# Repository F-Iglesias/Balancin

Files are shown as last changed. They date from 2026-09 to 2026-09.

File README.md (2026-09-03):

# A hand-made self balancing robot!

It balances itself with a PID control, measuring the angle 

## Third and final prototype


You can see a video of the robot moving [here](https://www.youtube.com/watch?v=WksrDXhgYMs)

### Main board



### Encoders (3D printed and designed by me)




<p align="center">

</p>

## Second prototype



[Here](https://youtube.com/shorts/iVz-gH_mcks?feature=share) is a video.

For this prototype I designed a simpler encoder, but since it was not able to read the direction in which the wheels rotated, it was useless for its purpose, so I discarded that design.

Captura encoder v1

## First prototype

Sadly I lost all the photos I had, but here are two videos:

[Video 1](https://youtube.com/shorts/Z38a0RHIttk?feature=share)

[Video 2](https://youtube.com/shorts/8MTNevPrN3k?feature=share)

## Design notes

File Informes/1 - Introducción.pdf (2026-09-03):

### Taller de Electrónica

Introducción

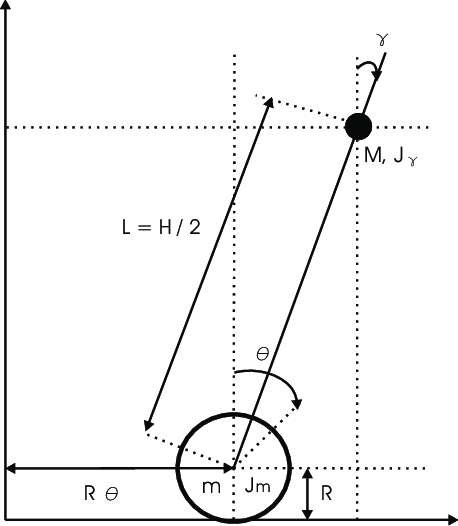
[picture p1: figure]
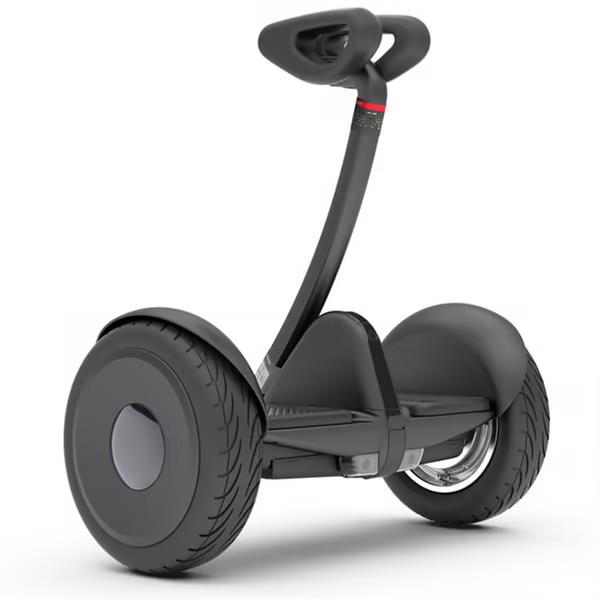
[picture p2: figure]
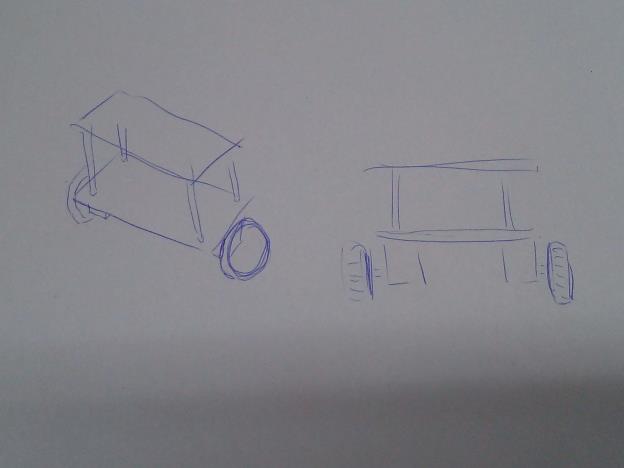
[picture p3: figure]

2024 1

## Introducción

La idea de nuestro proyecto es un robot equilibrista. Más específicamente, un robot que puede mantenerse equilibrado y maniobrar utilizando dos ruedas, que además pueda controlarse mediante Bluetooth.

Este robot puede modelarse como un péndulo invertido de dos ruedas: un sistema que consiste de un péndulo montado sobre dos ruedas que pueden girar libremente (fig 1.a). Este sistema es inestable, por lo que es muy utilizado para las pruebas de algoritmos de control. Un ejemplo comercial de este tipo de robots es el Segway (fig 1.b)

Fig 1.a: Esquema del péndulo invertido | Fig 1.b: Segway

Se puede ver el primer boceto de nuestro proyecto:

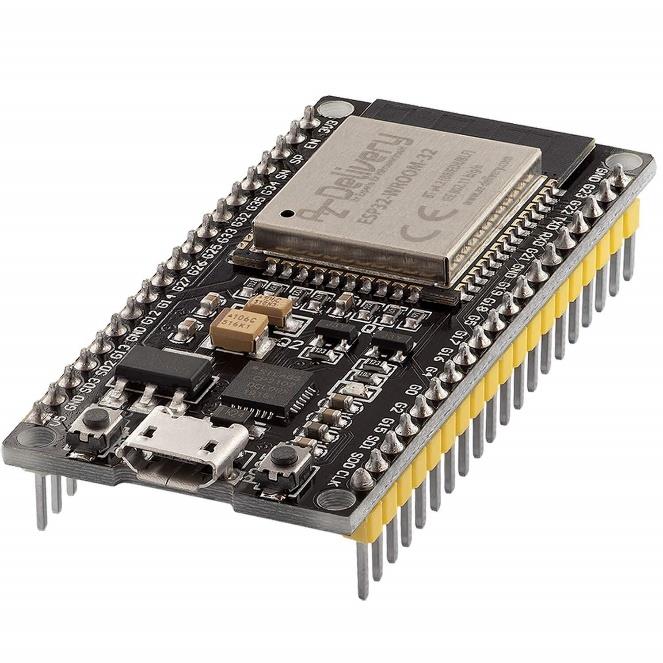
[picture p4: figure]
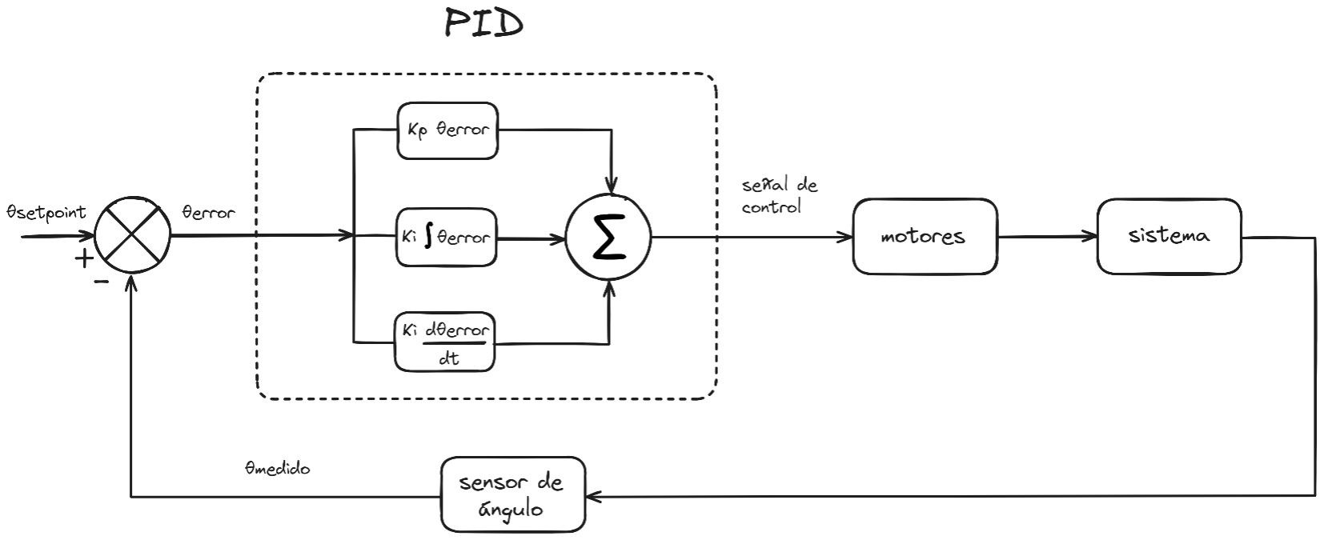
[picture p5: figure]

2024 2

La idea es que el robot mantenga el equilibrio controlando únicamente los motores. Claramente necesitamos cierta información del exterior, que obtendremos a partir de sensores. Para leer y procesar la información de los sensores e implementar la comunicación Bluetooth, usaremos un microcontrolador programable: el ESP32. Elegimos este porque ya viene con Bluetooth integrado y tiene librerías que nos facilitan implementar la comunicación, además de que puede programarse en el framework de Arduino con PlatformIO

Investigando, vimos que uno de los algoritmos de control más usados es el control PID, que podemos representar en el siguiente diagrama.

Vamos a considerar que θ es el ángulo de inclinación el robot. El setpoint será el ángulo al que queremos llegar, y el error la diferencia entre el setpoint y el ángulo medido.

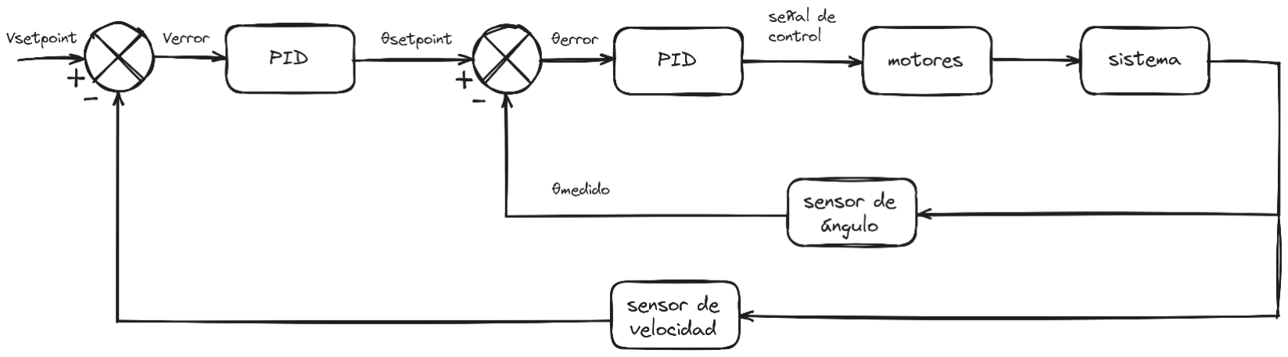
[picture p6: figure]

2024 3

θsetpoint − θmedido = θerror

El control PID (proporcional, integrativo, derivativo) es un sistema de control de lazo cerrado en el cual nuestra señal de control es una combinación lineal entre el error, su integral y su derivadal, dado por las constantes Kp, Ki y Kd.

señal de control = Kp ⋅ θerror + Ki ⋅ ∫ θerrordt + Kd ⋅

dθerror
dt

La eficacia de este sistema depende de qué tan bien ajustados estén los tres parámetros Kp, Ki y Kd

Ahora bien, si este sistema de lazo cerrado está bien afinado puede mantener al robot verticalmente de una forma muy estable, pero si queremos maniobrar (modificando el setpoint) el sistema se vuelve muy inestable. (checkear)

Se puede llegar a un sistema mucho más estable si añadimos otro lazo cerrado en cascada, que controle el setpoint de nuestro primer PID en función de la velocidad lineal del robot.
El sistema de se representa así:

Con esto ya hemos definido el algoritmo de control. Lo que queda es implementarlo en nuestro proyecto. Todos estos cálculos pueden realizarse fácilmente en el firmware, principalmente necesitamos es saber como:
- Controlar los motores
- Medir el angulo de inclinación
- Sintonizar el primer PID
- Medir la velocidad de las ruedas
- Sintonizar el segundo PID

En las siguientes partes veremos como hacer esto

2024 4

## Referencias

- https://es.wikipedia.org/wiki/Controlador_PID
- https://robotics.stackexchange.com/questions/17964/self-balancing-robot-pid-control-algorithm
- https://arxiv.org/ftp/arxiv/papers/2303/2303.12067.pdf

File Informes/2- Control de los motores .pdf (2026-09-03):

### Taller de Electrónica

Control PWM

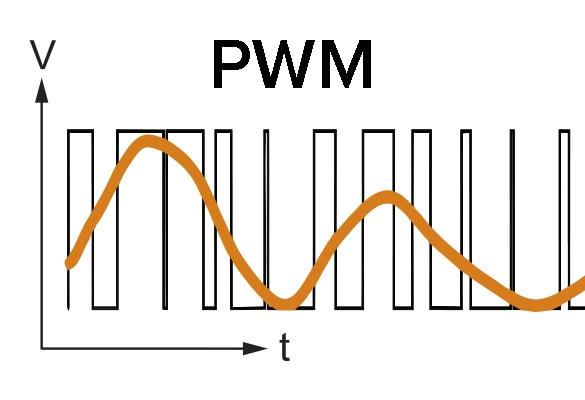
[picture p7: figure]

2024 1

## 2 - Control PWM

Para implementar correctamente nuestro péndulo invertido debemos tener una forma de controlar la velocidad de los motores desde nuestro microcontrolador.

La forma más común de hacer esto es mediante PWM (Modulación de ancho de pulso). El PWM es una técnica que consiste en generar una señal pulsante a frecuencia constante e ir variando el ciclo de trabajo..

Si conectamos un motor a un generador PWM, la velocidad del motor dependerá del ciclo de trabajo, es decir, que para un ciclo de trabajo fijo, el motor girará a velocidad constante. A frecuencias más altas, más preciso es nuestro control.

figura 2.1. La curva amarilla representa el valor promedio en cada momento de esta señal PWM

Entonces, lo que vamos a hacer es implementar un control PWM para el ESP32.

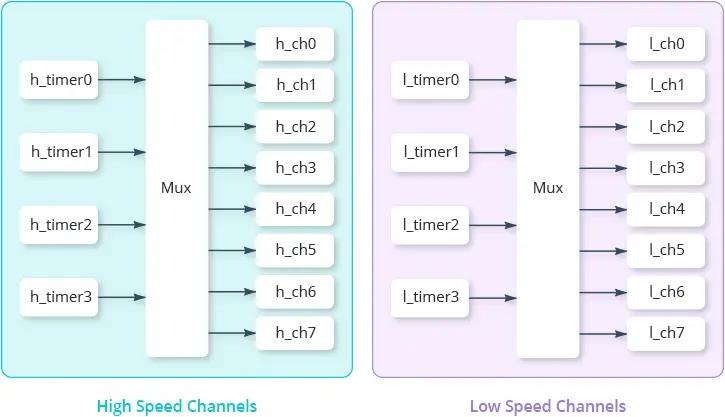
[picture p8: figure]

2024 2

## El código

El ESP32 tiene 16 canales internos de PWM, los primeros 8 de alta frecuencia y los otros de baja frecuencia.

Los canales de alta velocidad están implementados en el hardware, es decir que son independientes del procesador, mientras que los canales de baja frecuencia dependen del software para cambiar el ciclo de trabajo.

Como puede verse en la imagen anterior, cada 8 canales hay cuatro timers, por lo que cada temporizador es compartido por dos canales. Esto significa que los dos canales que compartan un mismo temporizador tendrán la misma frecuencia, pero su ciclo de trabajo se puede controlar de forma independiente. En nuestro caso esto no importa, ya que la frecuencia de PWM que vamos a usar para los motores va a ser la misma para cada salida.

Para generar una señal PWM, debemos “adjuntar” un canal de PWM a un pin GPIO. Es posible adjuntar el mismo canal a varios pines. El código es el siguiente:

2024 3

#include <Arduino.h>

//Definimos lo pines de salida del motor que se controla con un puente H

uint8_t pin1 = 2;

uint8_t pin2 = 16;

uint8_t ch0 = 0;

uint8_t ch1 = 1;

void setup()

{

int freq = 30000; //La frecuencia de la señal PWM. Usamos 30kHz ya que

está fuera de la frecuencia audible

int res = 1023; //La resolución del PWM

uint8_t res_bits = 10; //La misma resolución en bits

//Elegimos los canales de PWM

//Establece los pines como salida

pinMode(pin1, OUTPUT);

pinMode(pin2, OUTPUT);

//Establece la frecuencia y la resolución del PWM en los canales 0 y 1

ledcSetup(ch0, freq, res_bits);

ledcSetup(ch1, freq, res_bits);

//Adjunt los pines pin1 y pin2 a los canales ch0 y ch1, respectivamente

ledcAttachPin(pin1, ch0);

ledcAttachPin(pin2, ch1);

//Pone el ciclo de trabajo en 0 para que los motores estén apagados

ledcWrite(ch0, 0);

ledcWrite(ch1, 0);

}

Luego, en el loop, llamando a la función ledcWrite, podemos cambiar el ciclo de trabajo de los distintos pines.

2024 4

## Bibliografía

- https://lastminuteengineers.com/esp32-pwm-tutorial/#:~:text=PWM%20Channels,-Now%20let%20us&text=A%20channel%20represents%20a%20unique,and%208%20low-speed%20channels. (https://lastminuteengineers.com/esp32-pwm-tutorial/)
- https://randomnerdtutorials.com/esp32-pwm-arduino-ide/

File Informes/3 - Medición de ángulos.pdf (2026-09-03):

### Taller de Electrónica

Giróscopo - acelerómetro

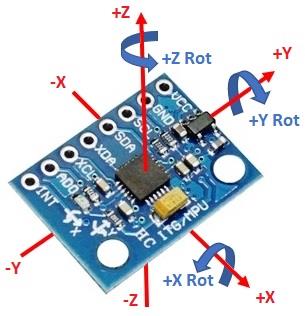
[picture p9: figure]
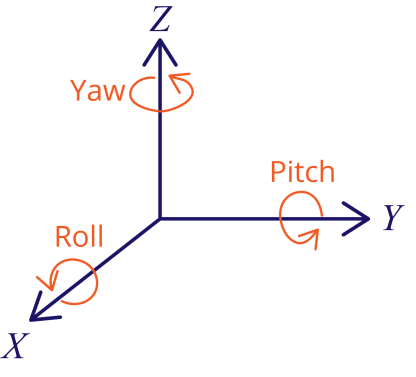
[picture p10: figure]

2024 1

## 3 - Unidad de medición inercial

Una unidad de medición inercial o IMU, es un dispositivo electrónico que mide e informa acerca de la velocidad, orientación y fuerzas gravitacionales de un aparato, usando una combinación de acelerómetros y giróscopos (wikipedia). (https://es.wikipedia.org/wiki/Unidad_de_medici%C3%B3n_inercial)

Para controlar a nuestro robot necesitamos saber su ángulo de inclinación. Lo más común es usar una IMU para esto. El módulo que usaremos es el MPU6050.

Los datos que nos da el MPU6050 son, la aceleración lineal y la velocidad angular en sus tres ejes (x, y, z). Como veremos más adelante, estos datos son suficientes para estimar el ángulo de inclinación de nuestro robot.

Convencionalmente, los ejes x, y, z se llaman roll, pitch y yaw.

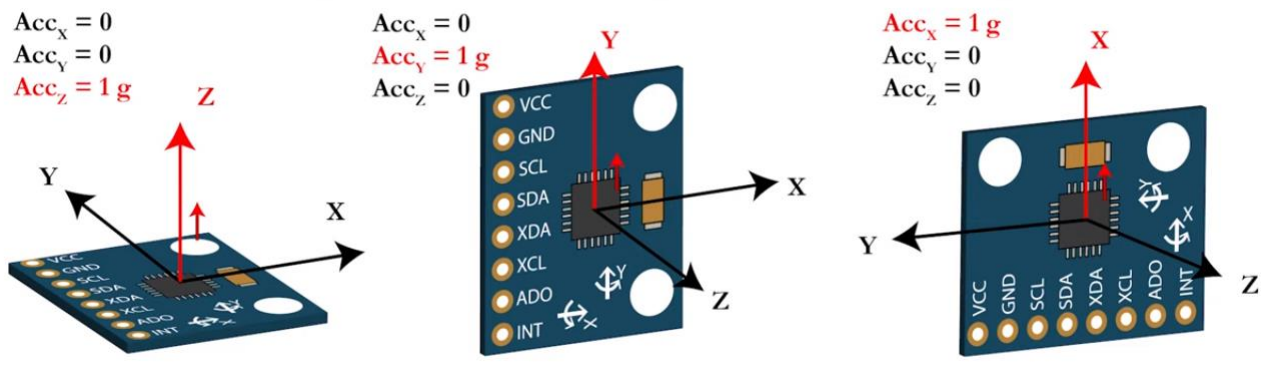
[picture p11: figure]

2024 2

## Midiendo la inclinación con el acelerómetro – método trigonométrico

Este método nos permite obtener una aproximación de los ángulos roll y pitch.

La fuerza de la gravedad siempre tiene la misma dirección, así que conocer su vector respecto a los ejes x, y, z del IMU nos permite conocer su orientación respecto al plano horizontal de la tierra.

Argumentos trigonométricos nos permiten llegar a las siguientes fórmulas:

θroll = arctan (
gy
√gx
2 + gz

2

)

θpitcℎ = arctan (
−gx
√gy
2 + gz

2

)

Donde gx, gy, gz
son las componentes de la gravedad en los ejes x, y, z del MPU. Véase que este método solo sirve para inclinaciones menores a ±90°. Y, en general, para ángulos muy cercanos a ±90° se vuelve impreciso por el comportamiento asintótico de vx √vy 2+vz

2

cuando el

vector v tiende a ser horizontal.

En el MPU6050, los ejes del acelerómetro funcionan como resortes, de modo tal que cualquier fuerza externa que actúa sobre él es captada. Es decir que, cuando la única fuerza que actúa es la de la gravedad, estamos midiendo el vector gravedad. La clave de este método consiste en despreciar toda perturbación externa a excepción de la gravitacional, de modo tal que la medición del acelerómetro es igual a g, es decir,

(Accx, Accy, Accz) ≅ (gx, gy, gz)

En este caso, tenemos:

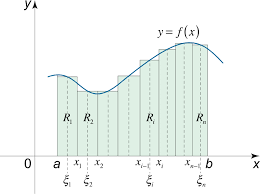
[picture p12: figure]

2024 3

θroll ≅ arctan(
Accy
√Accx
2+Accz

2

) | θroll ≅ arctan(
−Accx
| √Accy
2+Accz

2

)

## Midiendo la inclinación con el giróscopo – método integrativo

El giróscopo nos provee las velocidad angulares respecto de los ejes x, y, z, y, por definición, tenemos ω =

dθ
dt

, o equivalentemente

θ = ∫ ωdt

tf

ti

Por lo tanto, es posible obtener los ángulos de inclinación integrando la velocidad angular. Ahora bien, nosotros no podemos hallar exactamente el área bajo la curva de ω, pero podemos aproximarla mediante rectángulos, es decir, evaluando una suma de Riemann.

En este método, en cada iteración de nuestro bucle principal mediremos la velocidad angular ωk en el instante tk y aplicaremos la siguente fórmula recursiva

θk = θk−1 + ωk ⋅ Δtk

Esta entonces es una forma distinta de estimar el ángulo: mientras la anterior aprovechaba el acelerómetro, esta emplea al giróscopo.

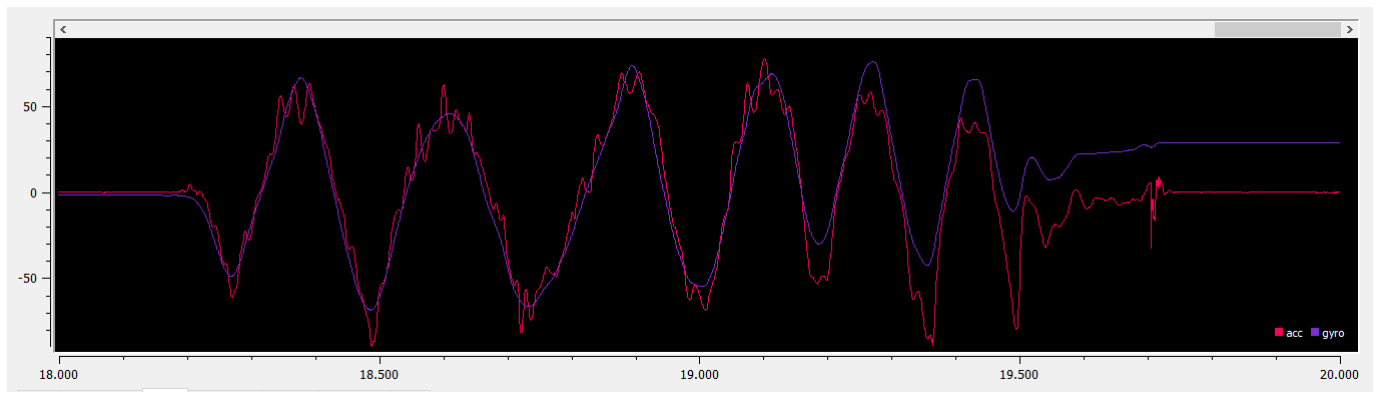
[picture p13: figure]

2024 4

## Ventajas y desventajas del método trigonométrico y del integrativo

Hasta ahora hemos visto dos formas de estimar el ángulo de inclinación: una utilizando al acelerómetro y otra usando al giróscopo. Ahora veremos las ventajas y desventajas de cada método.

Por un lado, el método trigonométrico tiene mucho ruido, ya que cualquier perturbación externa afecta a nuestra medición, mientras que el método integrativo produce una señal suave, ya que se necesita un pico muy grande y continuado de ω para producir un gran cambio en la señal.

Por el otro, el método trigonométrico tiene una señal sin desfase, las perturbaciones externas solo afectan nuestras mediciones mientras están presentes, por lo que si movemos el sensor durante unos segundos y lo volvemos a apoyar horizontalmente, el ángulo nos dará 0 de nuevo. Pero el método integrativo no nos garantiza eso, la acumulación de error es inevitable.

Puede verse como tras mover el sensor durante 6 segundos la señal del giróscopo se desfasó totalmente.

Como veremos ahora, hay un método, conocido como el filtro de Kalman, que nos permite aprovechar tanto al giróscopo como al acelerómetro, para eliminar estos problemas.

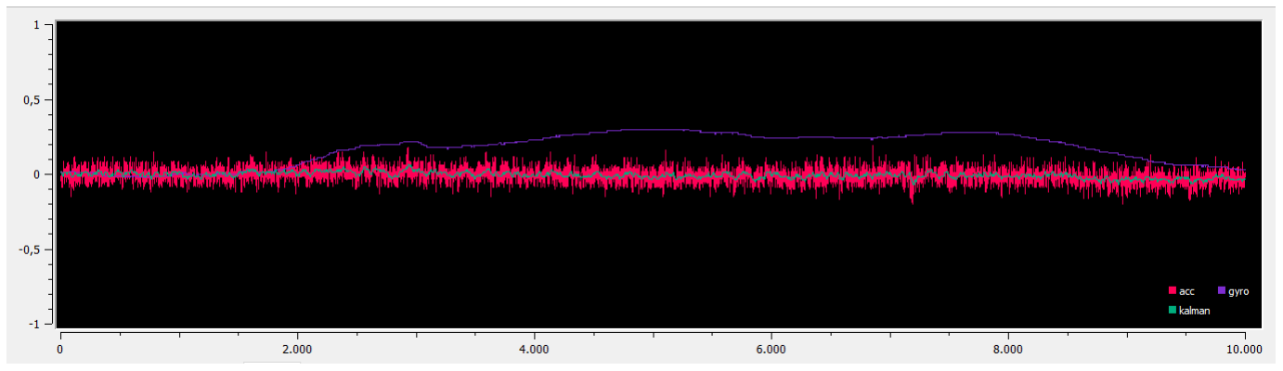
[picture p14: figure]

2024 5

## El filtro de Kalman

El filtro de Kalman es un algoritmo iterativo que nos permite aprovechar tanto al giróscopo como al acelerómetro para eliminar los problemas del método trigonométrico y del integrativo; es decir, para producir una señal con poco ruido y que no se desfase a lo largo del tiempo.

Este algoritmo tratará de estimar mediante métodos estadísticos el estado del sistema, basándose en las mediciones del estado actual y de los anteriores, empleando tanto al acelerómetro como al giróscopo. El desarrollo matemático está fuera del alcance de este texto, pero se puede leer más acerca en este artículo. (http://blog.tkjelectronics.dk/2012/09/a-practical-approach-to-kalman-filter-and-how-to-implement-it/)

Para implementar el filtro de Kalman en nuestro proyecto, tomamos la librería de este repositorio de github (https://github.com/TKJElectronics/KalmanFilter) y le hicimos algunas modificaciones.

Su implementación es sencilla. Para cáda ángulo que queramos medir creamos un miembro de la clase Kalman, y en nuestro bucle principal, llamamos al método Update, al cual le proporcionamos el ángulo obenido a partir del acelerómetro, la velocidad angular medida del giróscopo y el dt (delta time).

A continuación puede verse la comparación entre el filtro de Kalman con los otros métodos:

Cuando el sensor está en reposo. Puede verse que el ruido de la estimación del acelerómetro es mucho mayor al del filtro de kalman. También puede verse un desfase en la señal del giróscopo.

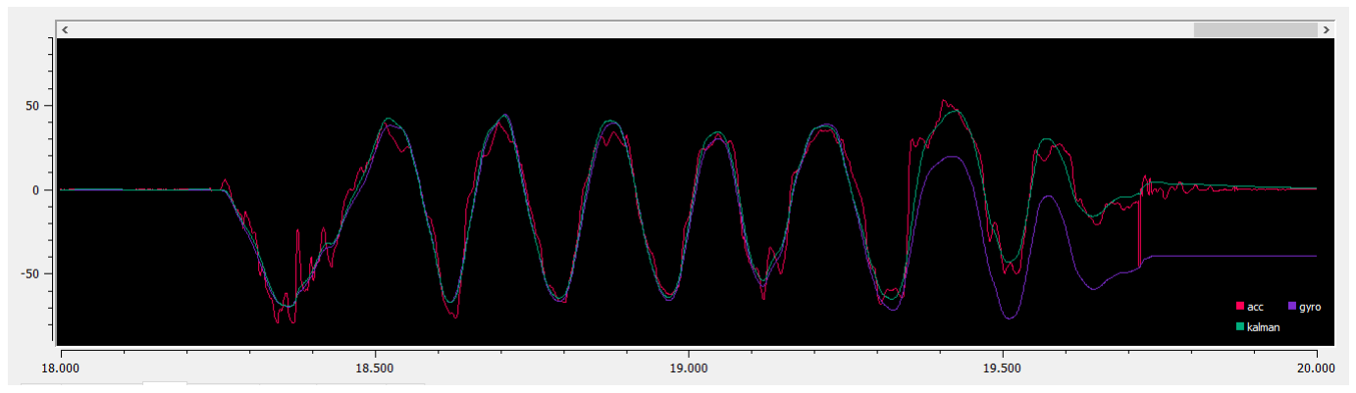
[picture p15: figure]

2024 6

En este caso giramos de un lado a otro el sensor. Nótese como la estimación acelerómetro tiene picos de ruido de hasta ±40° y como la estimación del giróscopo se desfasa hasta casi −30° tras 1500 mediciones (como estamos midiendo cada 4ms, esto significa que tardó solo 6 segundos en llegar a ese desfase). En este ejemplo podemos ver claramente las ventajas de usar el filtro de kalman.

2024 7

## Bibliografía

- https://es.wikipedia.org/wiki/Unidad_de_medición_inercial
- https://www.youtube.com/watch?v=7VW_XVbtu9k
- https://www.youtube.com/watch?v=5HuN9iL-zxU
- http://blog.tkjelectronics.dk/2012/09/a-practical-approach-to-kalman-filter-and-how-to-implement-it/

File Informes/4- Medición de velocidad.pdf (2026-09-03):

### Taller de Electrónica

Medición con de velocidad

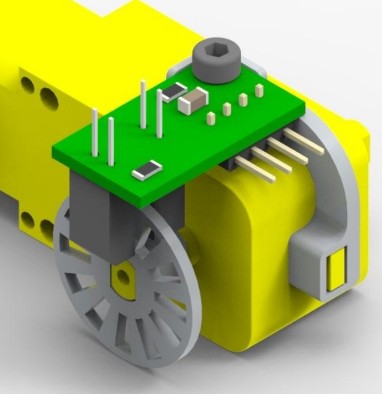
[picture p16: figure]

2024 1

## Medición de velocidad

Para completar nuestro sistema de control necesitamos una forma de medir la velocidad del robot. Esto equivale a medir la velocidad de los motores, ya que son proporcionales. Esto se puede hacer mediante el uso de encoders rotativos

Un encoder es un dispositivo electromecánico usado
para convertir la posición angular de un eje a señales
digitales.

Para el diseño de nuestro encoder nos inspiramos en el diseño de la figura 4.1. Este consiste en una rueda ranurada y un sensor de ranura que capta el giro.
Este tipo de encoder puede medir la rapidez del giro, pero no su sentido, por lo que

### Taller de Electrónica

Medición con de velocidad

2024 2

## Referencias

- https://en.wikipedia.org/wiki/Rotary_encoder

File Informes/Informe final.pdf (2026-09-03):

### Taller de Electrónica

Informe final


2024 1

## 1.Introducción

Nuestro proyecto consiste en un robot equilibrista de dos ruedas, es decir, en un robot que mediante el uso de dos ruedas debe mantener el equilibrio.

(INSERTAR IMAGEN 3D Y FOTO DEL ROBOT)

El modelo maemático de este sistema es el del péndulo invertido de dos ruedas (ver fig 1.a). Este sistema es inestable, por lo que el principal desafío es implementar el sistema de control que lo mantenga equilibtado. Un ejemplo comercial de este tipo de robots es el Segway (fig 1.b)

Fig 1.a: Diagrama del péndulo invertido | Fig: 1.b: Segway

Las dos variables medidas son, el ángulo de inclinación del robot y su velocidad lineal.

## 2. Desarrollo de la práctica

2024 2

Partimos de la idea de hacer un robot que utilizando únicamente dos ruedas pudiera mantenerse equilibrado.
Lo primero que hicimos fue ver otros proyectos del mismo tipo en internet, como estos por ejemplo:

Y de ahí hicimos nuestro primer boceto:

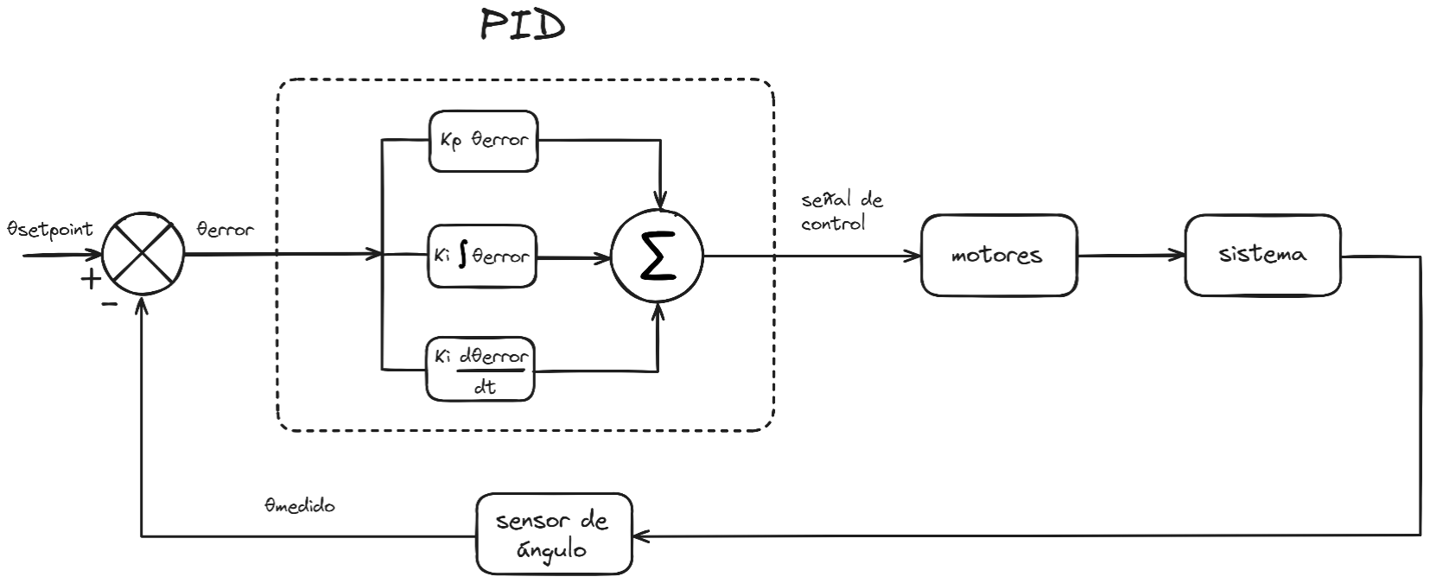
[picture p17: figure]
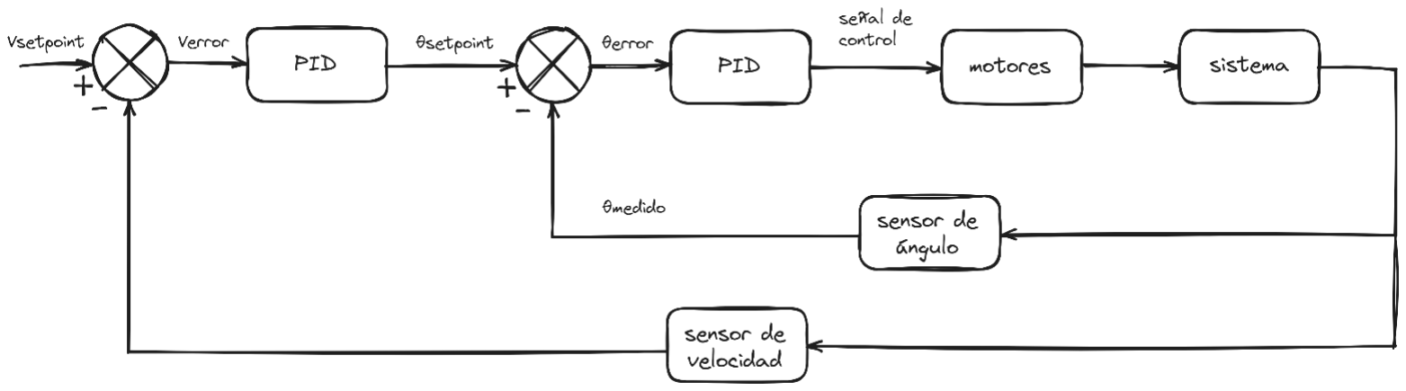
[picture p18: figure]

2024 3

Nuestro robot puede pensarse como un péndulo invertido, siendo un sistema inestable que requiere de un algoritmo de control para mantenerse equilibrado. Muchos proyectos implementaban un control PID para controlar el ángulo de inclinación que medían a partir de un giróscopo/acelerómetro, enviando la señal de control a los motores:

En este caso se establece el setpoint en 0 para que el robot trate de mantenerse vertical (teniendo en cuentra que θ representa el ángulo entre el equilibrista y la vertical..

El problema de este sistema es que, aunque el error se mantenga dentro de cierto rango pequeño, estp no nos garantiza que el robot se quede quieto. Es decir, puede equilibrarse pero se desplaza de un lado a otro.

Una forma de resolver esto es añadiendo otro sistema de control en cascada, esta vez, teniendo en cuenta la velocidad lineal del robot, como puede verse en la siguiente imagen:

Este algoritmo es usado en los robots más profesionales, como los Segway por ejemplo, y es el que implementaremos nosotros.

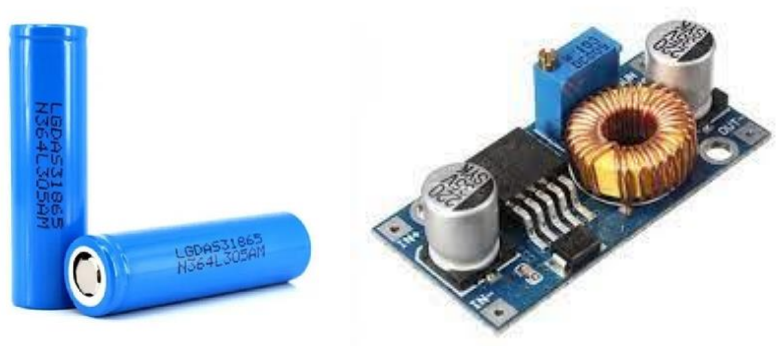
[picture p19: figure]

2024 4

## 2.1. Selección de componentes

Evidentemente necesitamos dos motores. En nuestro caso ya poseíamos dos motores DC de 12V, por lo que terminamos usando esos. En taller medimos una corriente máxima de 500mA por motor (poniendo resistencia en el eje), pero queríamos darle por lo menos 1A, ya que al arrancar siempre hay unos pequeños picos de corriente.

Cada motor debe poder girar en ambos sentidos, por lo que requerimos de un driver para motores. Escogimos el L9110s, ya que aguanta hasta 12V, 2A por motor. (Ver hoja de datos)

Para implementar nuestro sistema de control es conveniente usar un microcontrolador, ya que nos facilita los cálculos y nos permite establecer una comunicación serial. El que elegimos es el ESP32, que claramente puede efectuar los cálculos matemáticos necesarios, además de tener comunicación Bluetooth integrada, que tenemos pensado usar para comunicarnos desde la computadora, a fin de graficar ciertas variables y calibrar las constantes PID.

Para la alimentación utilizamos baterías 18650 a recomendación de los profesores. Como necesitabamos 12V utilizamos 4 baterías en serie, para llegar a 14,8-16,8V, y luego lo regulamos con un step-down. Elegimos un step-down por su eficiencia, ya que necesitabamos 2A para controlar ambos motores, y nuestras baterías eran de 2200mAh, por lo que no podíamos perder potencia innecesariamente usando un regulador lineal. El módulo que

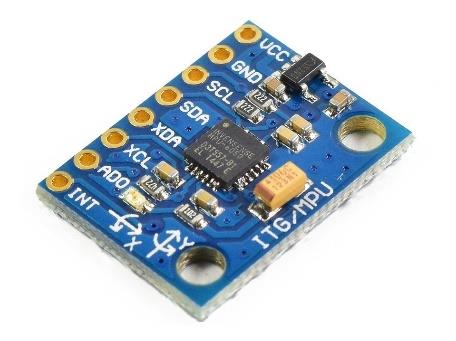
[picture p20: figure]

2024 5

compramos utiliza el integrado XL4005. .

Para la estimación del ángulo, el módulo usado en todos los proyectos que vimos era el giróscopo/acelerómetro MPU6050.

Luego, para medir la velocidad lineal, podíamos medir la velocidad de los motores que es proporcional. Para ello utilizaríamos encoders. Nosotros decidimos diseñar un encoder óptico de dos canales a partir del diseño de un tp de otro curso de 5to año.

## 2.2. Diseño y fabricación del PCB

2024 6

Nuestro PCB debe incluír entonces, borneras para conectar los motores y las baterías, el step-down para alimentar los motores, el puente H, un regulador de 5V para el ESP32, el ESP32 y salidas para conectar los sensores. El esquemático es el siguiente:

Se puede ver que añadimos un diodo Schottky BAT85 para proteger de tensiones inversas y un conector para un sensor de proximidad (HC-sr04).

Y el PCB:

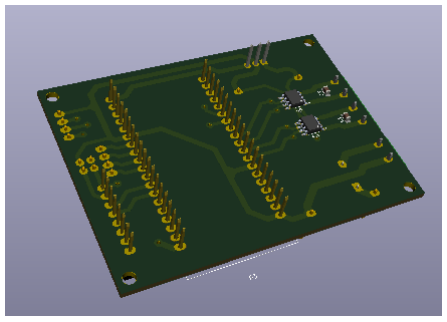
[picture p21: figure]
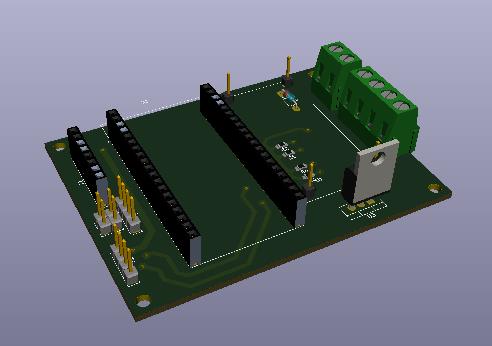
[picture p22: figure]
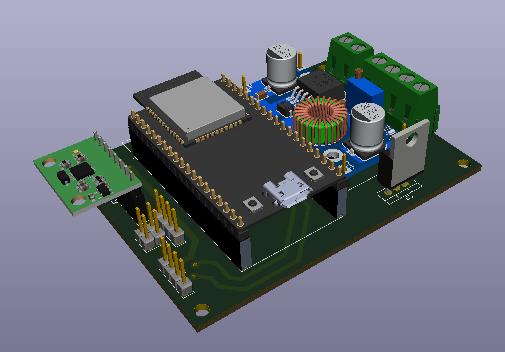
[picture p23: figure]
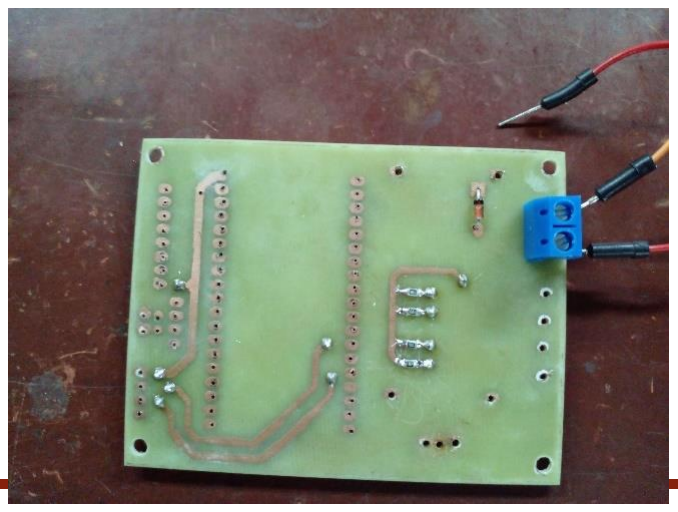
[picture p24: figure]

2024 7

Lo que decidimos es desoldar los componentes del driver para motores y soldarlos a la placa, pero dejar el módulo step-down intacto, soldado encima de la placa, ya que al poseer vías térmicas es más seguro así. Los conectores para los distintos sensores son tiras de pines.
Los modelos 3D son o de la librería de Kicad o de Grabcad.

Para hacer este diseño vimos como se conectan el MPU6050 y los encoders. En nuestro caso vamos a usar dos encoders de dos canales cada uno, por lo que se necesitan cuatro pines del ESP32.

Finalmente se planchó, procesó y agujereó el PCB:


2024 8

Mientras soldabamos, íbamos midiendo las tensiones para comprobar que todo funcione bien.

## 2.3. Medición del ángulo de inclinación

El primer sensor que debemos probar es el MPU. Este sensor se comunica por I2C. Nosotros utilizamos la librería de Arduino Wire.h para implementar esta comunicación.
para medir el ángulo de inclinación de nuestro robot.

Lo que nos dá el MPU es la aceleración (acelerómetro) y la velocidad angular (giróscopo) para todos los ejes. Con estos dos datos hay dos formas de estimar el ángulo: Por trigonometría o por integración


2024 9

La primera consiste en despreciar toda fuerza externa a la gravitacional, asumiendo que el vector de aceleración que se mide es el de la gravedad. A partir de este vector, podemos por trigonometría obtener los ángulos de inclinación

Por otro lado, a partir de las medidas del giróscopo, podemos integrar la velocidad angular y también obtener una estimación del ángulo

Estos métodos tienen sus ventajas y desventajas. El primero tiene mucho ruido, pero se puede confiar en sus mediciones largo plazo, el segundo tiene poco ruido, pero se desfaza por la acumulación de error al integrar, por lo que solo se puede confiar al corto plazo en sus valores.

El algoritmo que utilizamos se llama filtro de Kalman, y emplea tanto al giróscopo como al acelerómetro, y al estado anterior para hacer su estimación.

La librería que nos permite implementar el filtro de Kalman la sacamos de este repositorio de github. (https://github.com/TKJElectronics/KalmanFilter)

Luego hicimos varias pruebas comparando los distintos métodos. Los gráficos se hicieron con el programa SerialPlot.

En la primera prueba compramos el ´método trigonométrico con el integrativo, girando el sensor de un lado a otro. Puede verse como el trigonométrico tiene grandes picos de ruido y el integrativo se termina desfasando

2024 10

En la segunda prueba comparamos las tres mediciones con el sensor en reposo.

Finalmente comparamos las tres mediciones:

## 2.4. Diseño y fabricación del encoder óptico


2024 11

Como dijimos antes, para diseñar los encoders nos basamos en otro diseño:

Como podemos ver, consiste de una rueda ranurada y un sensor de ranura (TCST1103). Nosotros usamos el mismo sensor.

Primero diseñamos las placas:


2024 12

Y teniendo en cuenta sus medidas diseñamos el soporte:


2024 13

Como podemos ver, los sensores de ranura se hallan desfasados 15°, por lo que nuestra rueda ranurada es de 30°, dándonos una resolución de 24 pulsos por giro.


2024 14

Se puede ver el ensamble

Luego procesamos las placas e imprimimos los soportes y las ruedas en la impresora 3D:


2024 15

## 2.6. El código

Para el código, usamos dos loops, uno corriendo en un núcleo distinto. Un bucle se encarga de la comunicación y otro de la lógica de control, o sea, de la lectura de sensores, de los cálculos del PID, de accionar los motores.

Además, separamos todo en clases. Por ejemplo, si queremos controlar al MPU6050, creamos un miembro de la clase MPU6050 (imu en nuestro código) y símplemente con llamar al método Update(dt), se actualiza el ángulo. Esto porque la comunicación I2C y los cálculos del filtro de Kalman se hacen dentro de esta función. También creamos la clase Motor y la clase Encoder. Esto nos permite modificar el código de una manera mucho más sencilla
Entonces, el bucle de control corre siempre igual, cambiando en función de las variables que modifiquemos en el bucle de comunicación.AW30


2024 16

## 2.6. Diseño y armado del chasis

Teniendo en cuenta los encoders, diseñamos el chásis y cortamos la madera (front y back):

2024 17

Luego imprimimos unos soportes para motores

Y finalmente armamos el robot:

2024 18

## 2.7. Puesta en marcha

Finalmente, cargamos el código y empezamos a calibrar el robot. Primero calibramos Kp, hasta que en un valor de 8 se mantenía oscilando con un poco de ayuda humana. Luego aumentamos Kd, hasta 0,5. En este punto la señal se vuelve suave más suave, pero si el robot se va hacia un lado no puede recomponerse. Finalmente calibramos Ki a 100. En este punto el robot se mantenía de forma estable, pero ´su posición no era exacta. Para eso estaban los encoders.
Finalmente calibramos la constante Kenc a 0.1, aplicando Kenc*contador_encoder al setpoint del PID. En este punto se alcanzó un equilibrio estable.

## 4.Hojas de dato e información de los componentes


2024 19

ESP32:

L9110S:


2024 20

XL4005 (step-down)

El circuito de nuestro módulo:


2024 21

TSCT1103

2024 22

## 5. Conclusiones

Realizando esta práctica aprendimos como implementar un sistema de control utilizando varios sensores.

Fue interesante observar la comparación entre los distintos métodos de medir el ángulo, y ver como el filtro de Kalman superaba las desventajas de los demás métodos.

Finalmente, pudimos ver intuitivamente qué hacían las constantes PID sobre el robot.
La constante Kp permitia que oscile, pero no le daba un equilibrio estable, la Kd suavizaba más el movimiento (al oponerse a los cambios bruscos) y la Ki daba el ajuste fino; Finalmente, los encoders permitian mantener la posición exacta.

2024 23

## 6. Referencias

- https://es.wikipedia.org/wiki/Controlador_PID
- https://robotics.stackexchange.com/questions/17964/self-balancing-robot-pid-control-algorithm
- https://arxiv.org/ftp/arxiv/papers/2303/2303.12067.pdf
- https://lastminuteengineers.com/esp32-pwm-tutorial/#:~:text=PWM%20Channels,-Now%20let%20us&text=A%20channel%20represents%20a%20unique,and%208%20low-speed%20channels. (https://lastminuteengineers.com/esp32-pwm-tutorial/)
- https://randomnerdtutorials.com/esp32-pwm-arduino-ide/
- https://es.wikipedia.org/wiki/Unidad_de_medición_inercial
- https://www.youtube.com/watch?v=7VW_XVbtu9k
- https://www.youtube.com/watch?v=5HuN9iL-zxU
- http://blog.tkjelectronics.dk/2012/09/a-practical-approach-to-kalman-filter-and-how-to-implement-it/

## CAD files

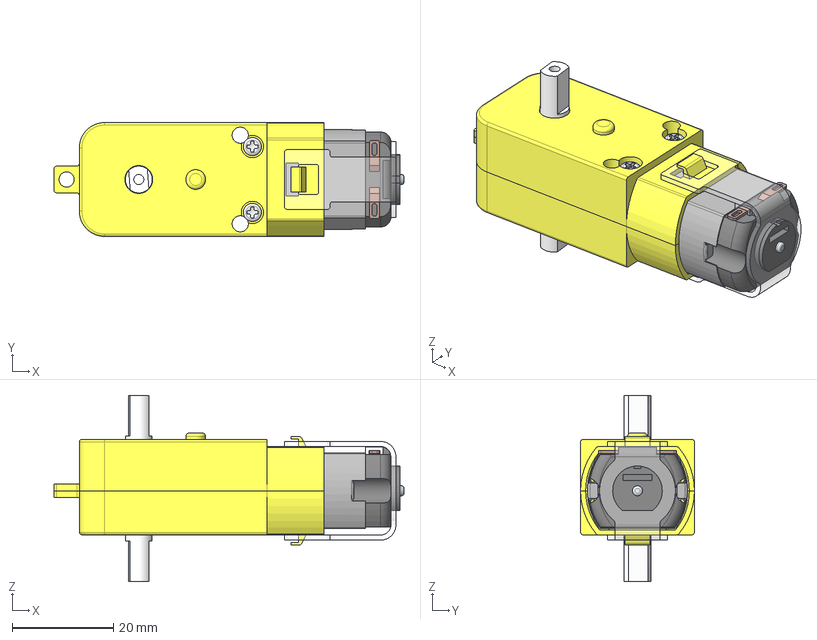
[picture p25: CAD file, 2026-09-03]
Archivos 3D/DC motor.stp
69.1 x 22.5 x 36.8 mm
Moteur - Enveloppe partie 1
Moteur - Engrenage 1
Moteur - Engrenage 2
Moteur - Moteur
Moteur - Axe engrenage
Moteur - Vis x 2
Moteur - Enveloppe partie 2
Moteur - Maintien
Moteur - Engrenage 3
Moteur - Engrenage 4

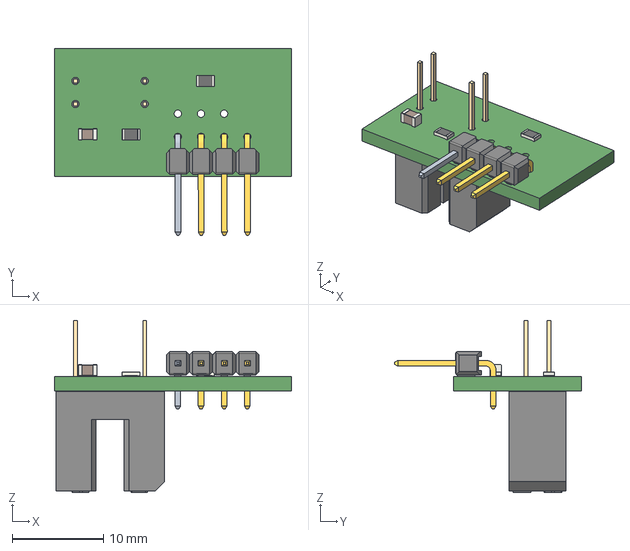
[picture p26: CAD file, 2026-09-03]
Archivos 3D/Encoder/Encoder1_PCB/Encoder óptico.step
26.0 x 20.5 x 18.9 mm

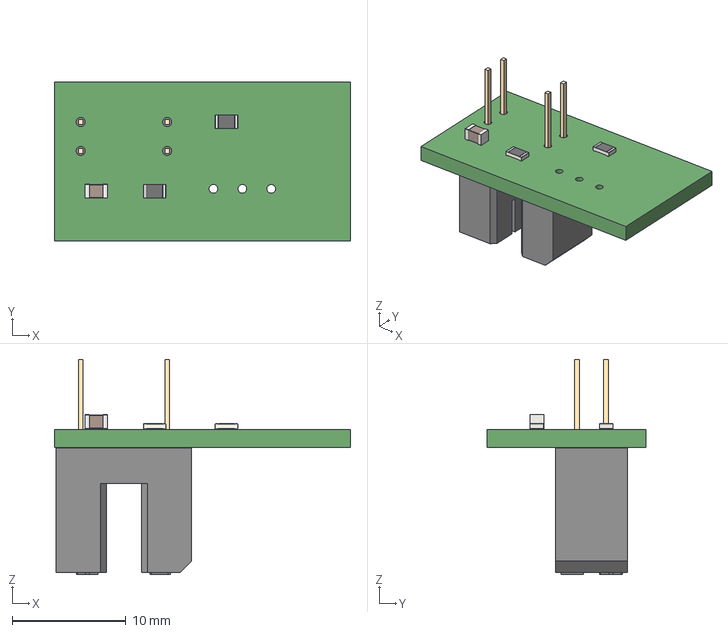
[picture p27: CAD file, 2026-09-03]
Archivos 3D/Encoder/Encoder2_PCB/Encoder óptico tipo 2.step
26.0 x 14.0 x 18.9 mm

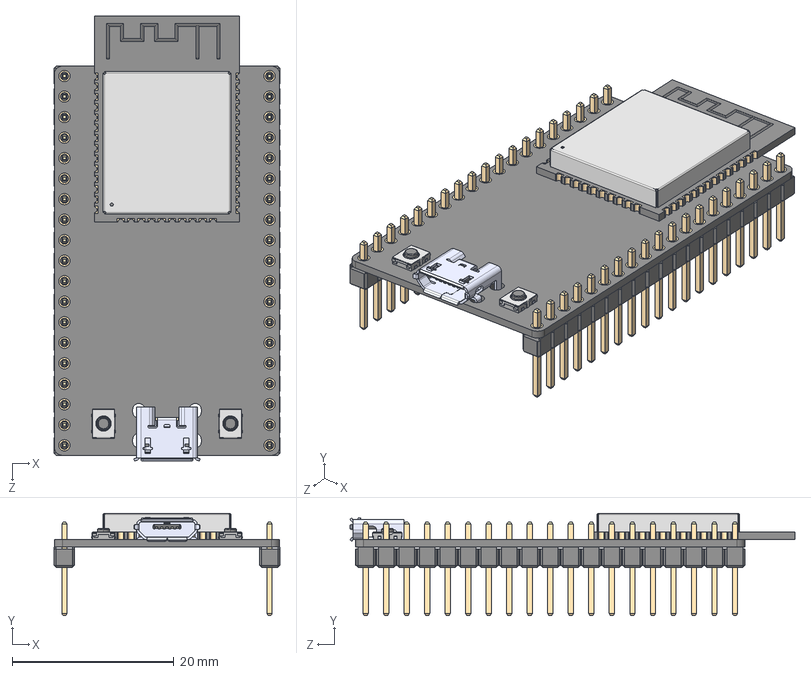
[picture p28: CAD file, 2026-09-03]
Archivos de Kicad/Kicad 5/Librería de footprints/3D/ESP32-DEVKITC-32D.step
27.9 x 12.7 x 55.1 mm
board
header x 2
ESP32-WROOM-32D
micro usb
button x 2

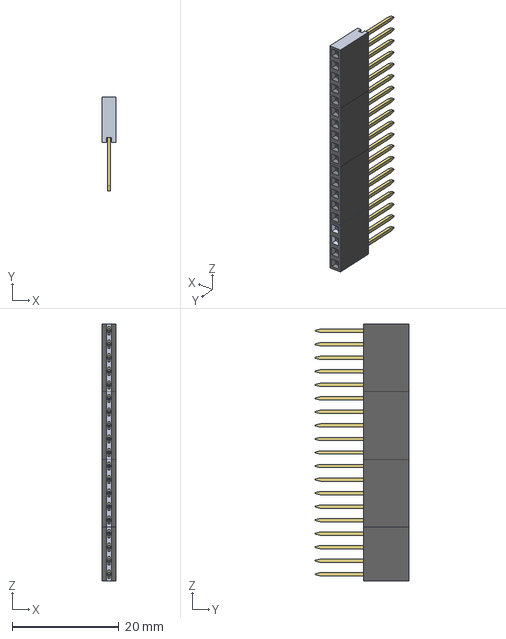
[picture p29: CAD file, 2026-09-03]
PCBs/Kicad 5/Librería de footprints/3D/Pin Header female 1x19.stp
2.54 x 17.6 x 48.3 mm
1x4
1x5 x 3

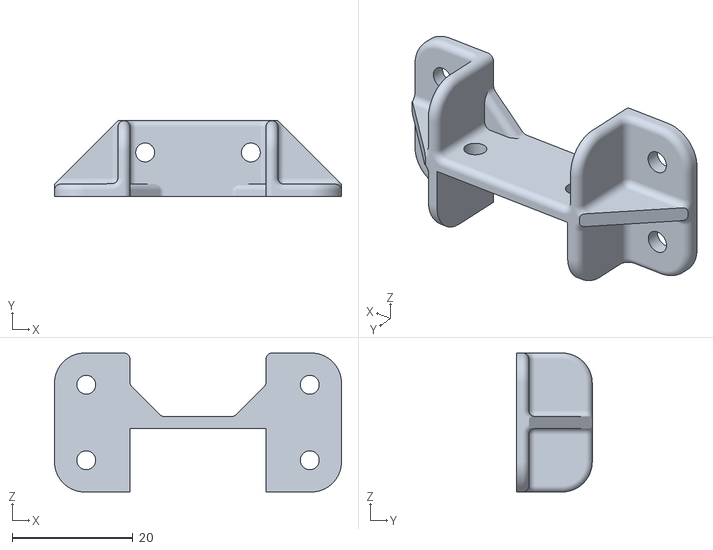
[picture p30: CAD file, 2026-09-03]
Archivos 3D/soporte para motor.stl
47.5 x 12.5 x 23.0

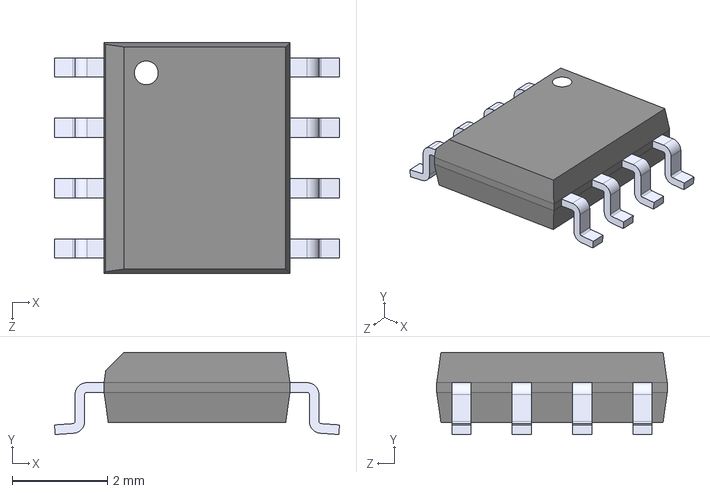
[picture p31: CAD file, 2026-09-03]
Archivos de Kicad/Kicad 5/Librería de footprints/3D/L9110S.step
5.99 x 1.73 x 4.85 mm

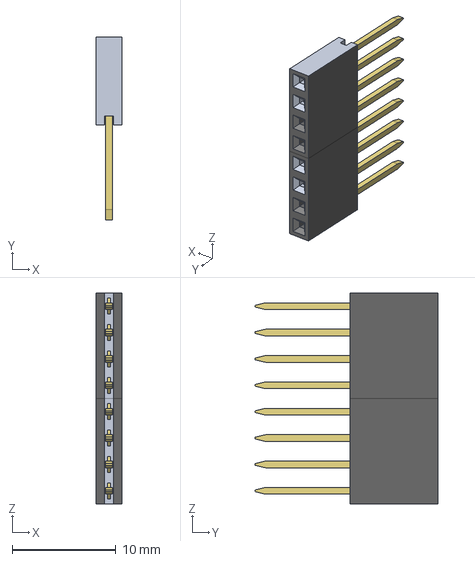
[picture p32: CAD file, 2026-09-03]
PCBs/Kicad 5/Librería de footprints/3D/Pin Header female 1x8.stp
2.54 x 17.6 x 20.3 mm
1x4 x 2

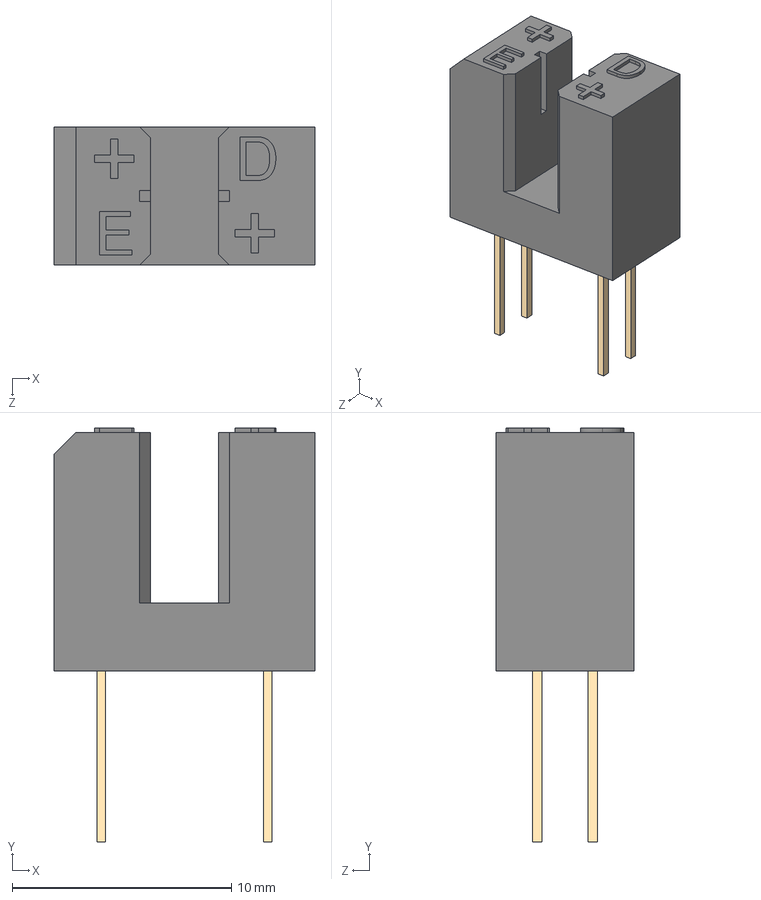
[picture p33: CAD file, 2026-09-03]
Archivos de Kicad/Kicad 5/Librería de footprints/3D/TCST1103.step
11.9 x 18.9 x 6.30 mm

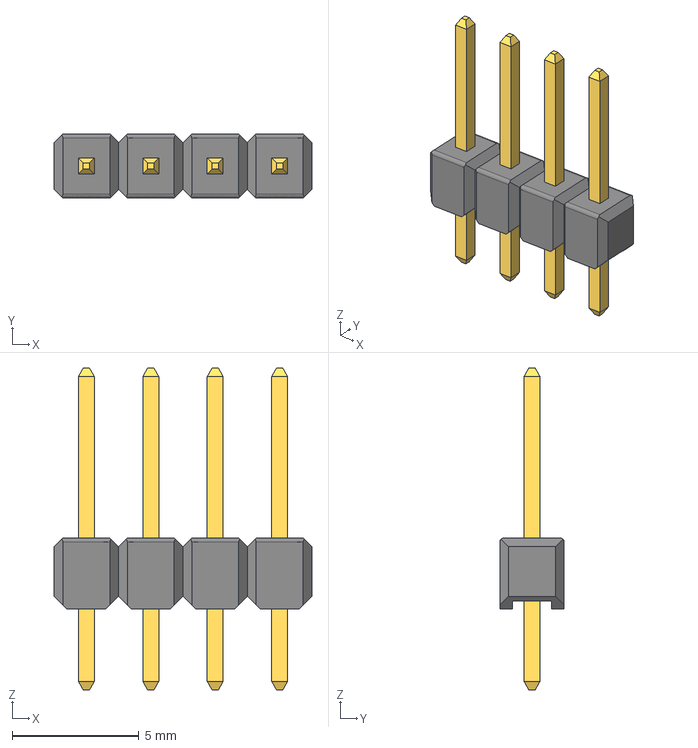
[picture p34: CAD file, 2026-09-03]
Archivos de Kicad/Kicad 5/Librería de footprints/3D/Pin Header 1x4 TH Pitch 2.54mm.stp
10.2 x 2.54 x 12.7 mm

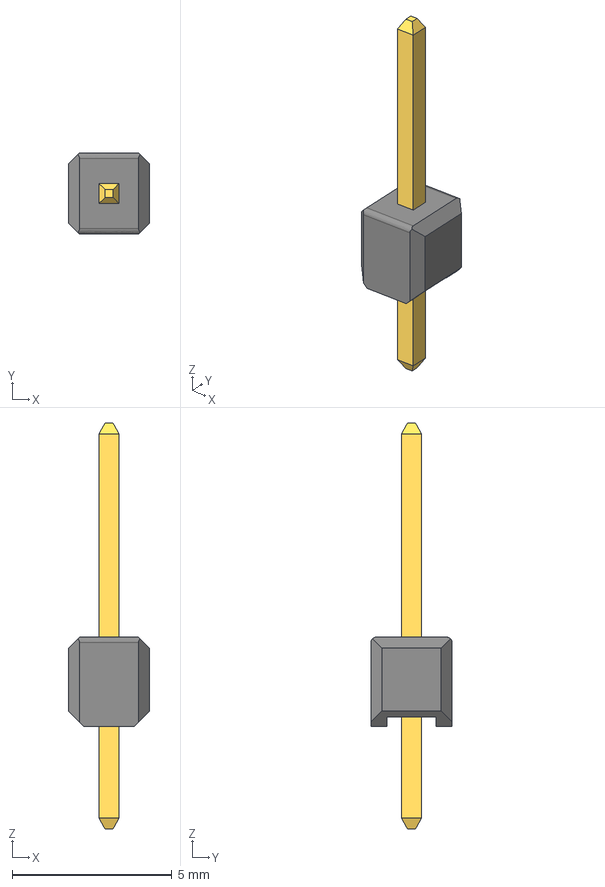
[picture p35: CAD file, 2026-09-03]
PCBs/Kicad 5/Librería de footprints/3D/Pin Header 1x1 TH Pitch 2.54mm.stp
2.54 x 2.54 x 12.7 mm

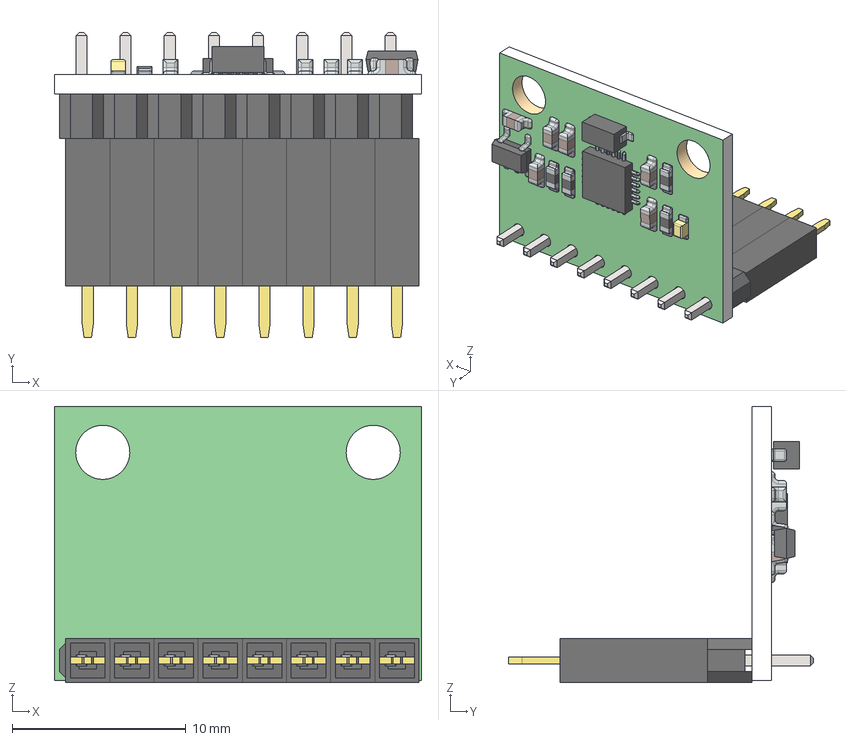
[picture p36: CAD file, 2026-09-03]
Archivos de Kicad/Kicad 5/Librería de footprints/3D/MPU-6050-on-female-header.step
21.1 x 17.6 x 15.9 mm
Base
pin header x 8
sensor chip
S2NH chip
Resistor small x 6
Resistor small black x 4
Small LED
Resistor black
SIL_Socket_Body x 8
SIL_SocketPin x 8

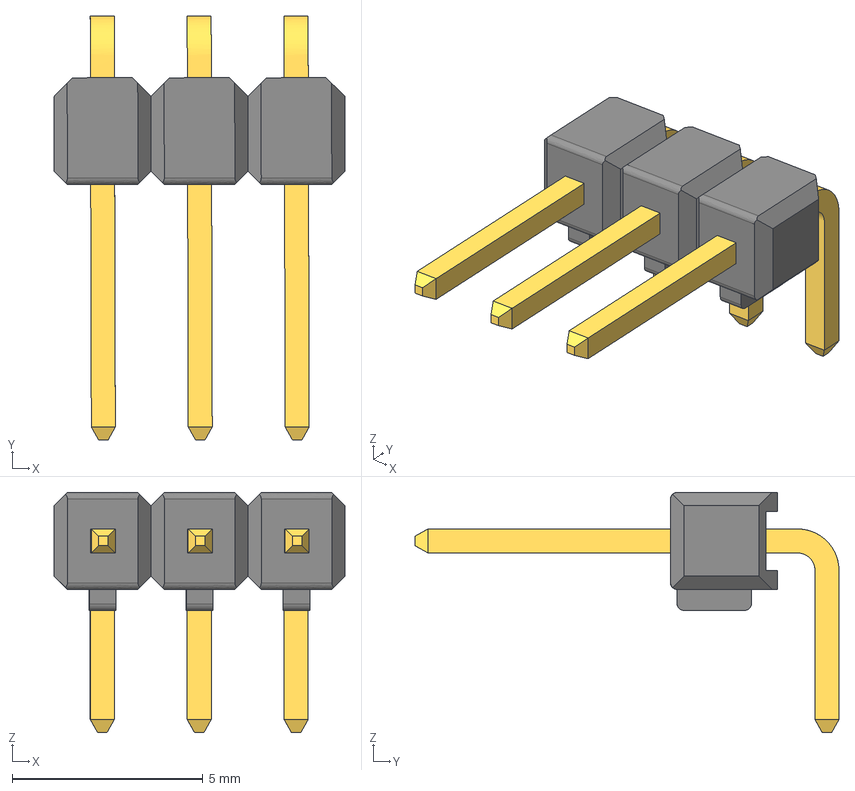
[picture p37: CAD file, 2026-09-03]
PCBs/Kicad 5/Librería de footprints/3D/Pin Header 1x3 TH Angle Pitch 2.54mm.stp
7.63 x 11.1 x 6.29 mm

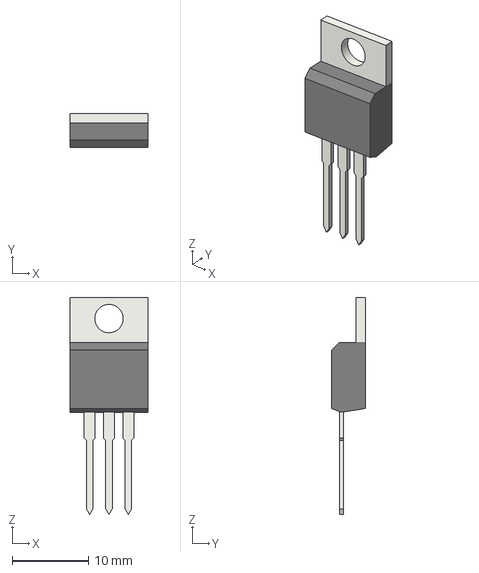
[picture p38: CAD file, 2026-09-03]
Archivos de Kicad/Kicad 5/Librería de footprints/3D/TO-220-3_Vertical.step
10.2 x 4.46 x 28.5 mm

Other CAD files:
Archivos de Kicad/Kicad 5/Librería de footprints/3D/R_0805_2012Metric.step
PCBs/Kicad 5/Librería de footprints/3D/Pin Header 1x4 TH Angle Pitch 2.54mm.stp
Archivos de Kicad/Kicad 5/Librería de footprints/3D/C_0805_2012Metric.step
Archivos de Kicad/Kicad 5/Librería de footprints/3D/Pin Header 1x2 TH Pitch 2.54mm.stp
Archivos de Kicad/Kicad 5/Librería de footprints/3D/Pin Header 1x4 TH Angle Pitch 2.54mm.stp
Archivos de Kicad/Kicad 5/Librería de footprints/3D/Terminal Block 2P.step
Archivos de Kicad/Kicad 5/Librería de footprints/3D/XL4005_MODELO_3D_1.step
PCBs/Kicad 5/Librería de footprints/3D/C_0805_2012Metric.step
PCBs/Kicad 5/Librería de footprints/3D/Pin Header 1x2 TH Pitch 2.54mm.stp
PCBs/Kicad 5/Librería de footprints/3D/R_0805_2012Metric.step
PCBs/Kicad 5/Librería de footprints/3D/Terminal Block 2P.step
PCBs/Kicad 5/Librería de footprints/3D/XL4005_MODELO_3D_1.step

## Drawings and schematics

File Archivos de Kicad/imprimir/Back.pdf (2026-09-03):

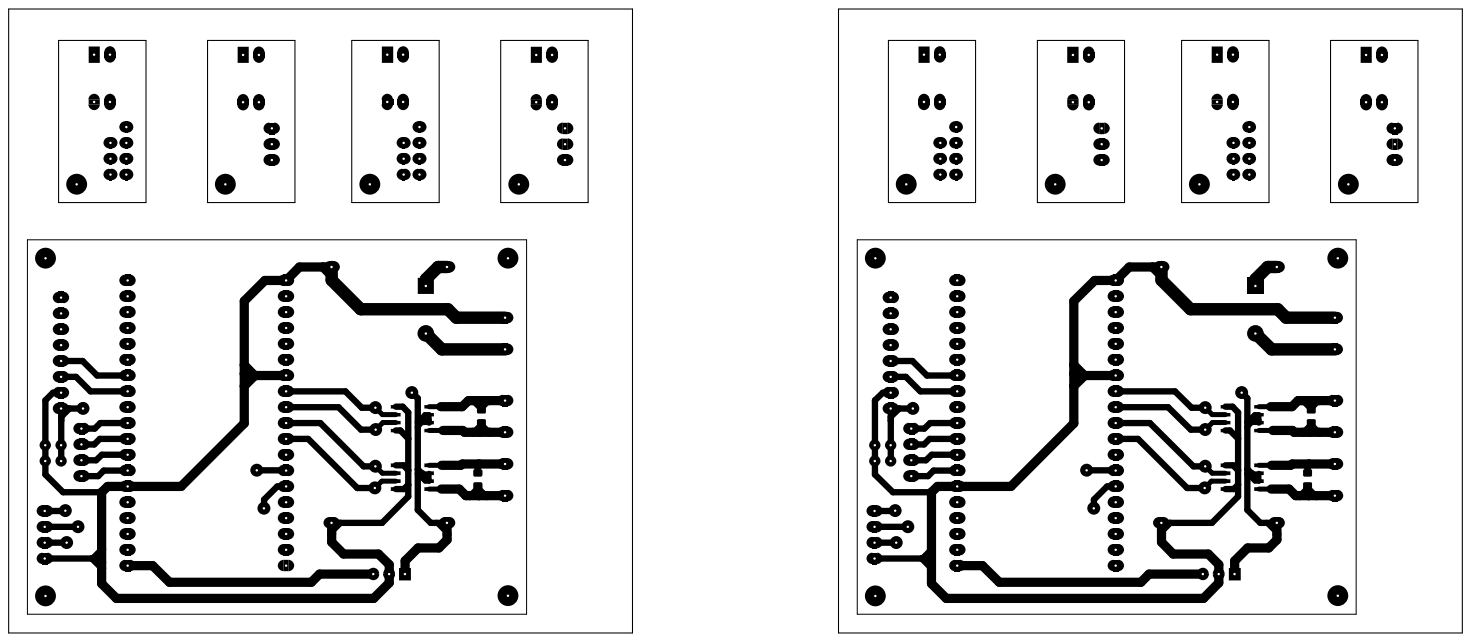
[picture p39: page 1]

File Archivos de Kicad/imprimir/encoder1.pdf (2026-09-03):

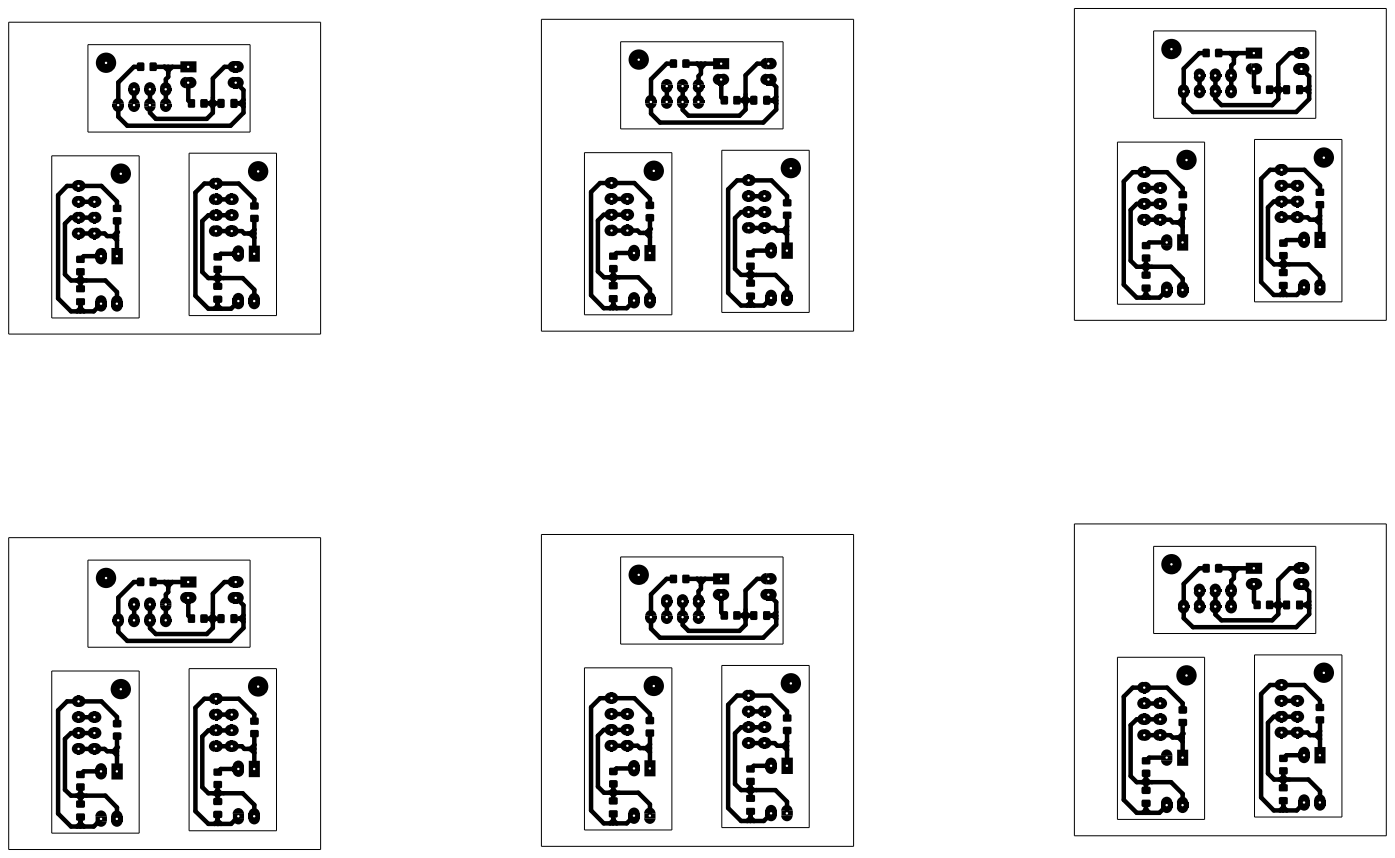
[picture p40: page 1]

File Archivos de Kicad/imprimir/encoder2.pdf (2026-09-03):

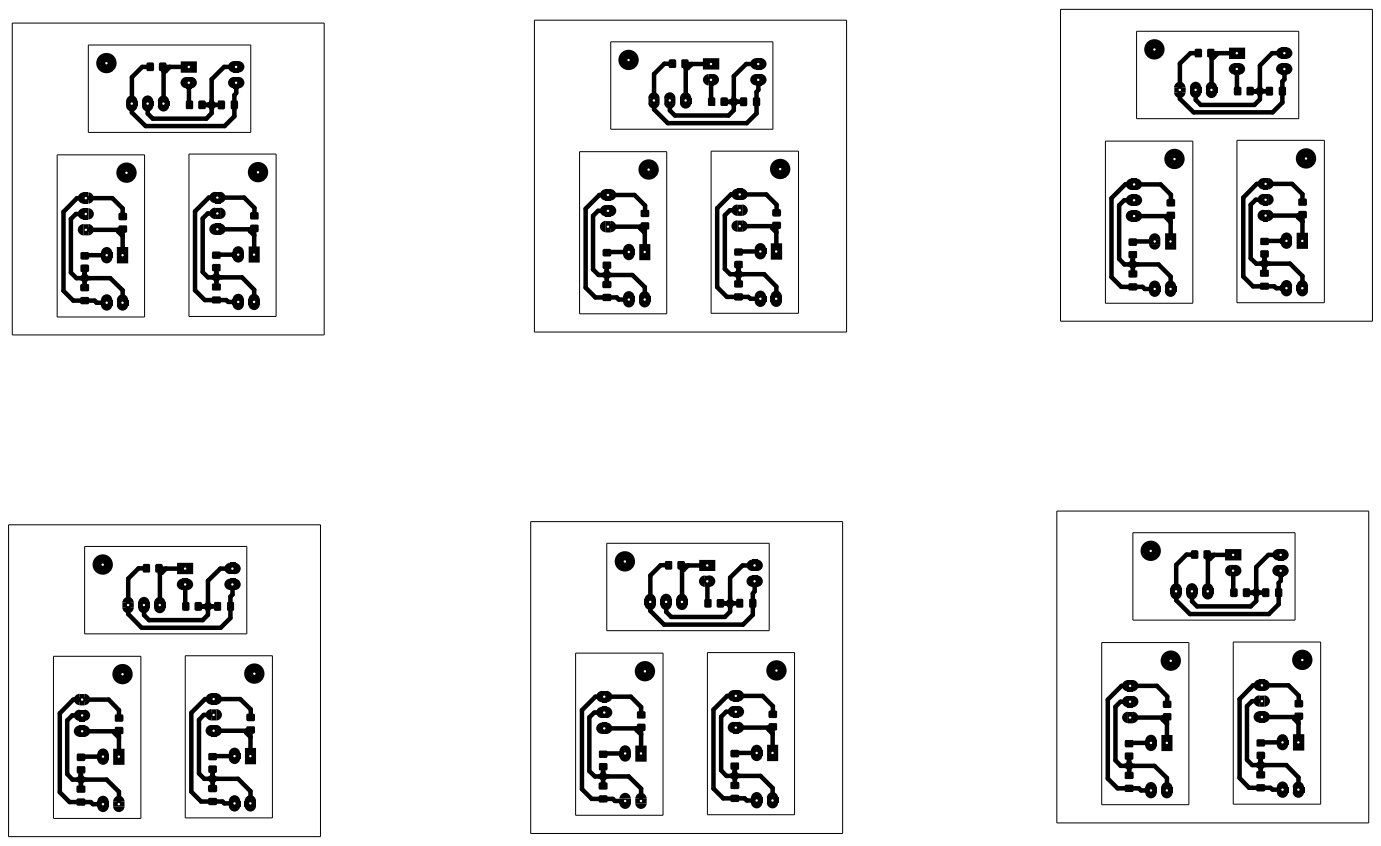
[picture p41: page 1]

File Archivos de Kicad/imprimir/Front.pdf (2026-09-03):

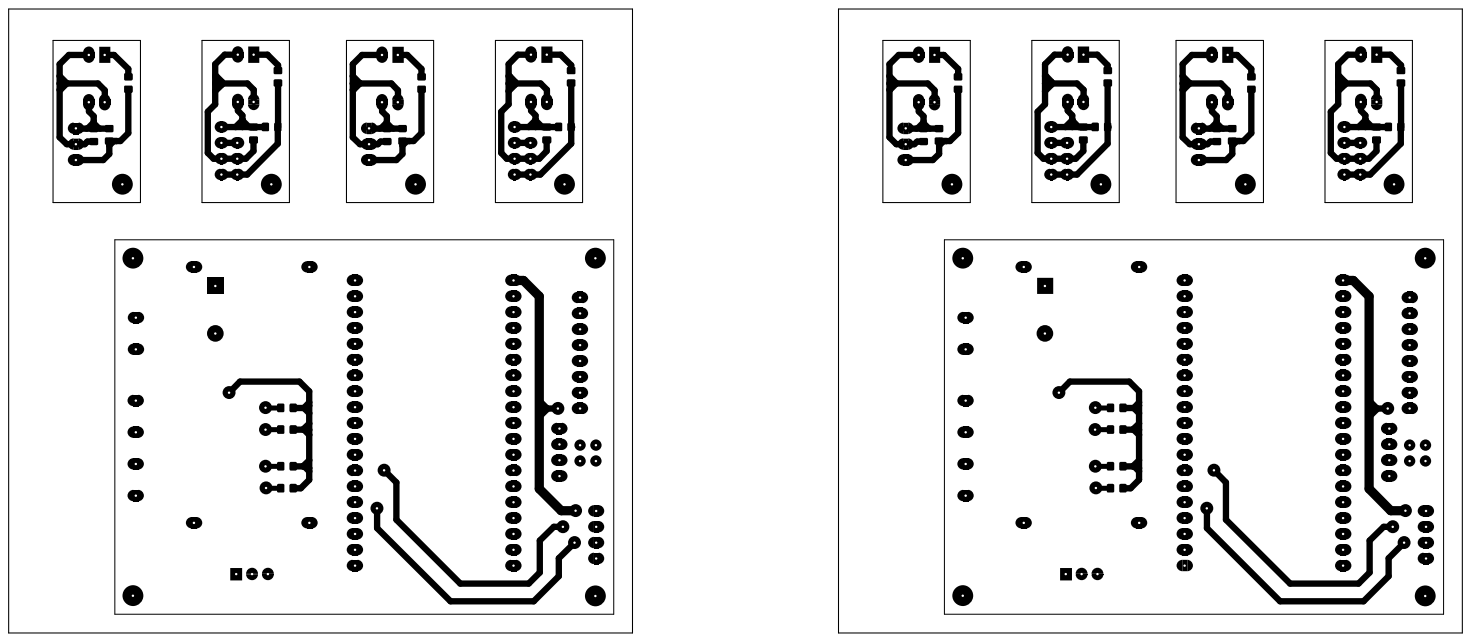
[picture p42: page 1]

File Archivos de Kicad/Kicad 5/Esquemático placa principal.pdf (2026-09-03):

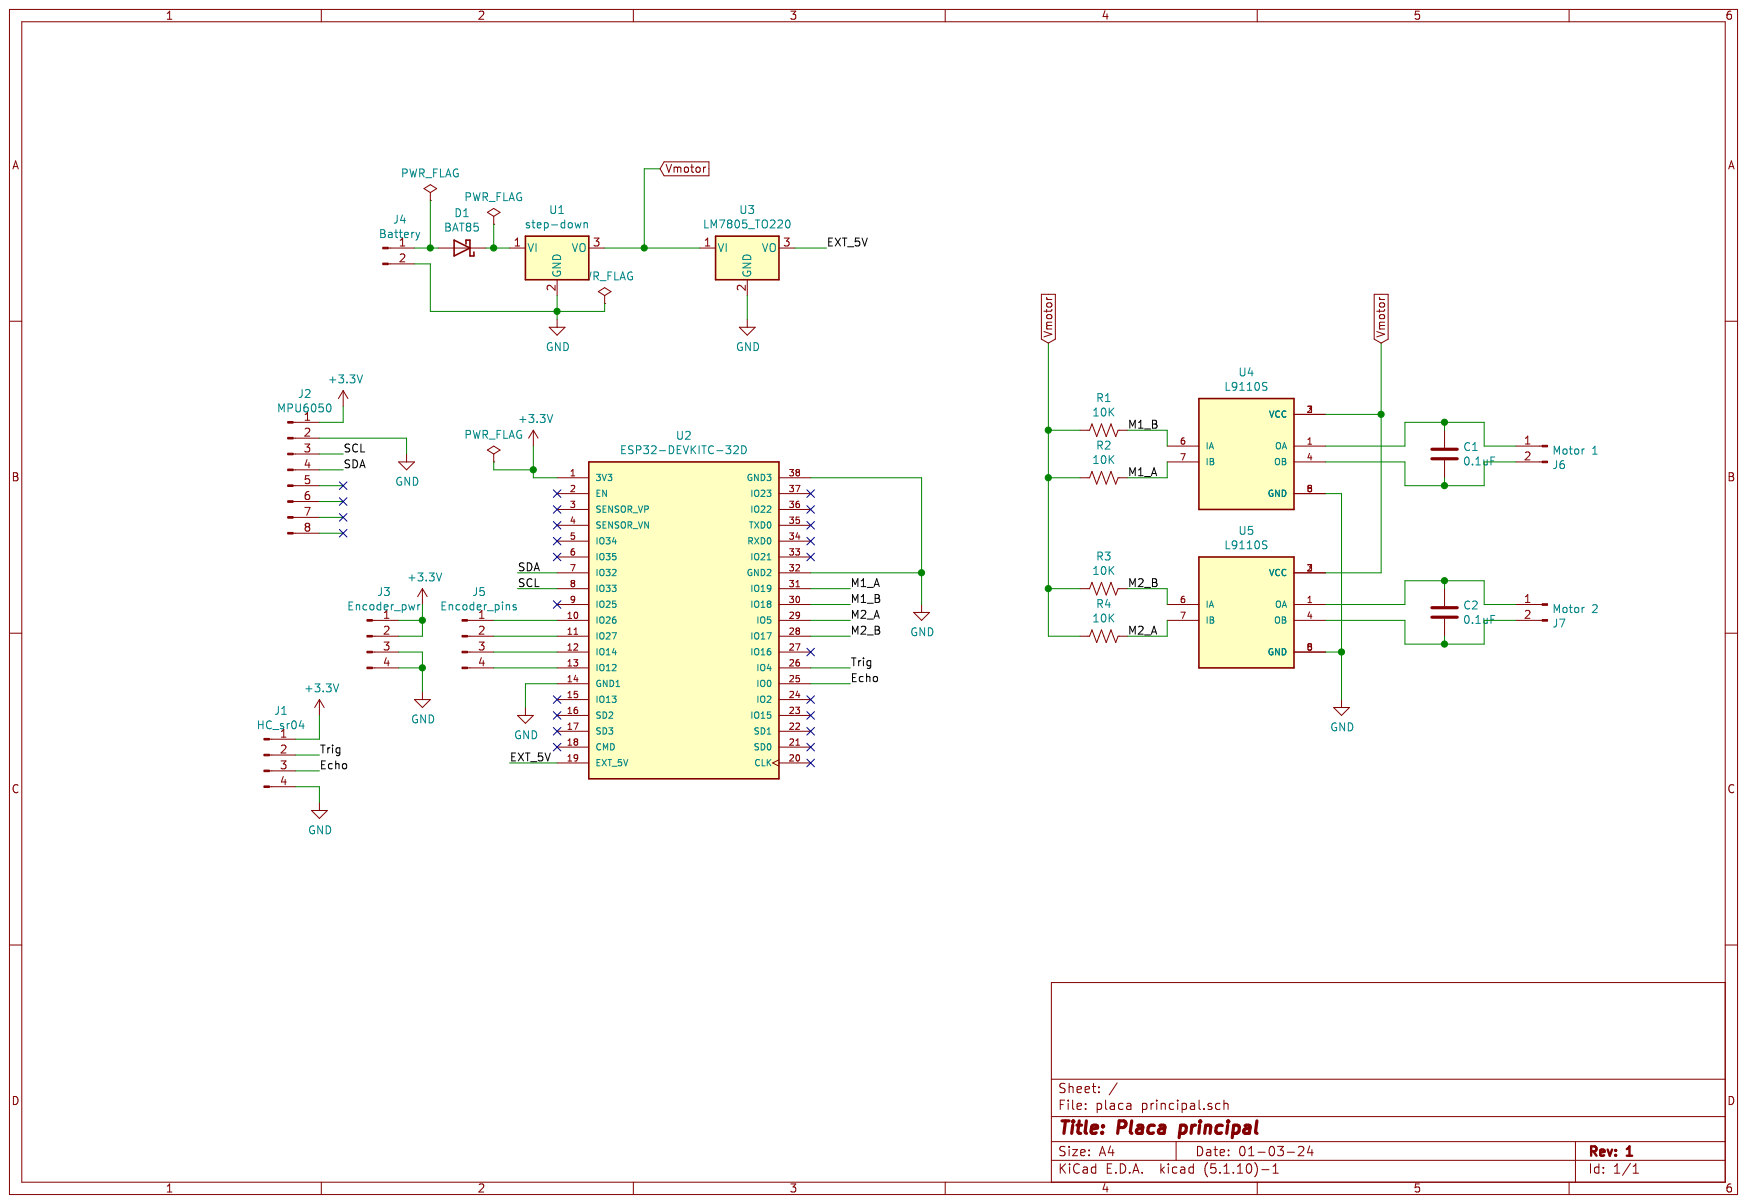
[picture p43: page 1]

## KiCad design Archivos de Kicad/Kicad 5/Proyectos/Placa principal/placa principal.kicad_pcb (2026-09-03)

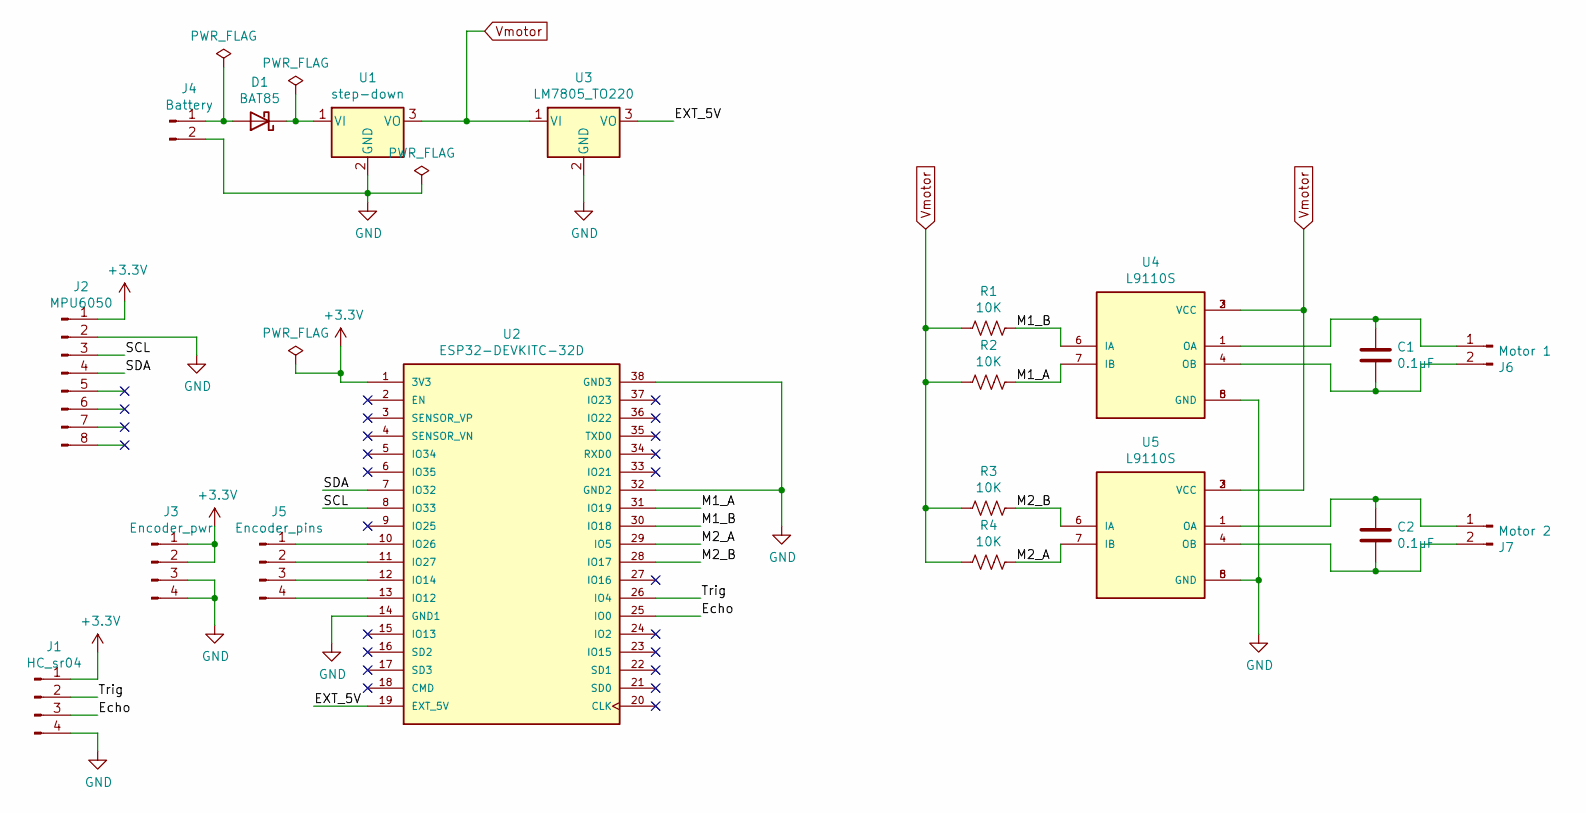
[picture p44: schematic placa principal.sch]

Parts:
C1, C2: 0.1uF; C_0805_HandSolder
D1: BAT85
J1: HC_sr04; HC-sr04
J2: MPU6050
J3: Encoder_pwr
J4: Battery; Bornera(5,08mm)
J5: Encoder_pins
J6: Motor 1; Bornera(5,08mm)
J7: Motor 2; Bornera(5,08mm)
R1, R2, R3, R4: 10K; R_0805_HandSolder
U1: step-down; XL4005_Module
U2: ESP32-DEVKITC-32D; MODULE_ESP32-DEVKITC-32D; PARTREV V4
U3: LM7805_TO220; TO-220-3_Vertical
U4, U5: L9110S; L9110s; PARTREV NA

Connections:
+3V3: J1.1, J2.1, J3.1, J3.2, U2.1 (3V3)
/EXT_5V: U2.19 (EXT_5V), U3.3 (VO)
/Echo: J1.3, U2.25 (IO0)
/M1_A: R2.1, U2.31 (IO19), U4.7 (IB)
/M1_B: R1.1, U2.30 (IO18), U4.6 (IA)
/M2_A: R4.1, U2.29 (IO5), U5.7 (IB)
/M2_B: R3.1, U2.28 (IO17), U5.6 (IA)
/SCL: J2.3, U2.8 (IO33)
/SDA: J2.4, U2.7 (IO32)
/Trig: J1.2, U2.26 (IO4)
GND: J1.4, J2.2, J3.3, J3.4, J4.2, U1.2 (GND), U2.14 (GND1), U2.32 (GND2), U2.38 (GND3), U3.2 (GND), U4.5 (GND), U4.8 (GND), U5.5 (GND), U5.8 (GND)
unnamed: C1.1, J6.1, U4.1 (OA)
unnamed: C1.2, J6.2, U4.4 (OB)
unnamed: C2.1, J7.1, U5.1 (OA)
unnamed: C2.2, J7.2, U5.4 (OB)
unnamed: D1.1 (K), U1.1 (VI)
unnamed: D1.2 (A), J4.1
unnamed: J5.1, U2.10 (IO26)
unnamed: J5.2, U2.11 (IO27)
unnamed: J5.3, U2.12 (IO14)
unnamed: J5.4, U2.13 (IO12)
Vmotor: R1.2, R2.2, R3.2, R4.2, U1.3 (VO), U3.1 (VI), U4.2 (VCC), U4.3 (VCC), U5.2 (VCC), U5.3 (VCC)

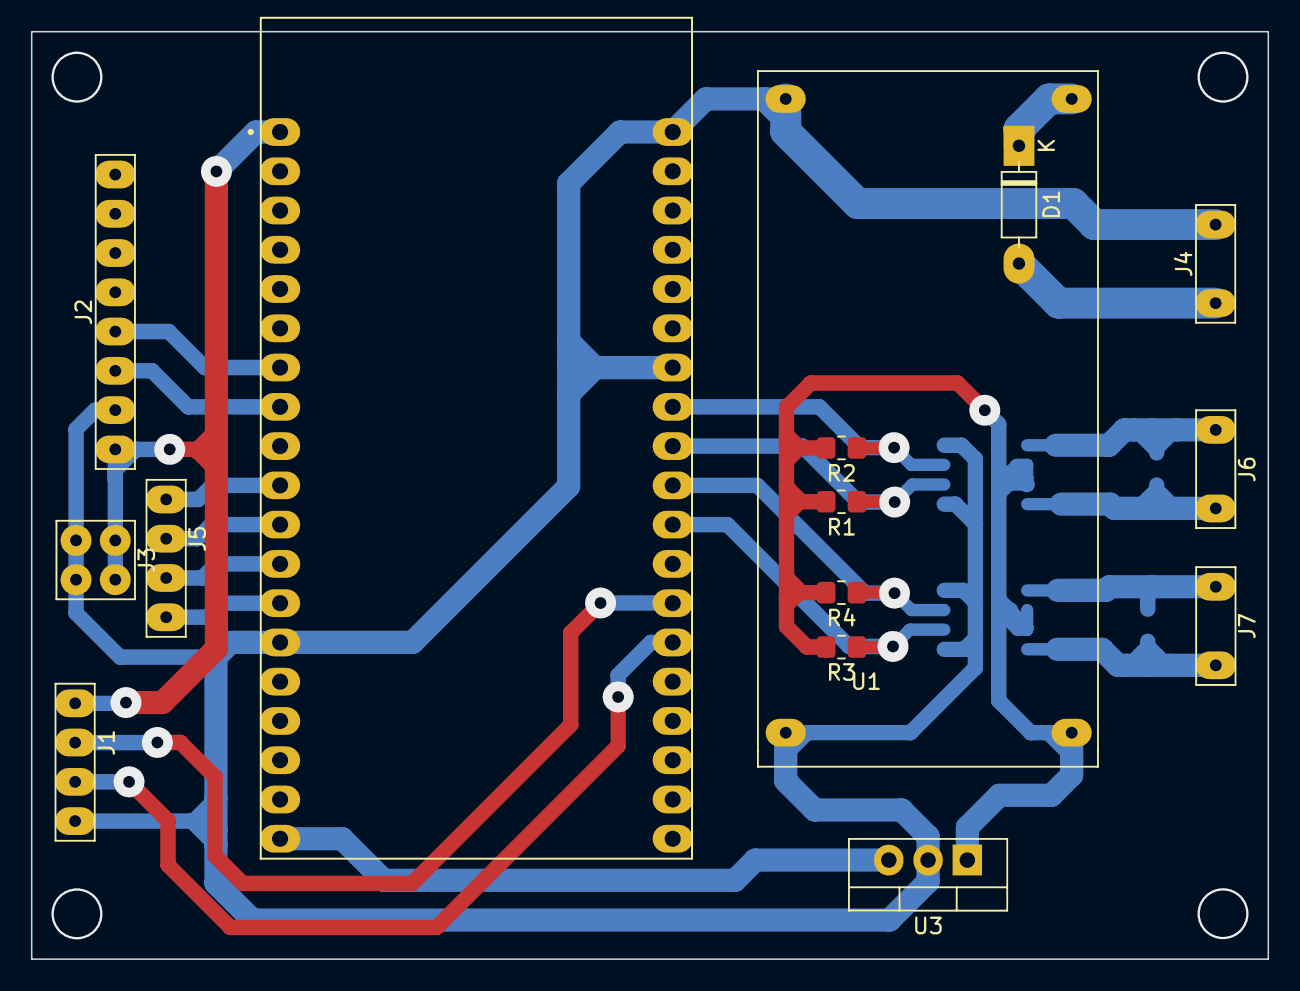
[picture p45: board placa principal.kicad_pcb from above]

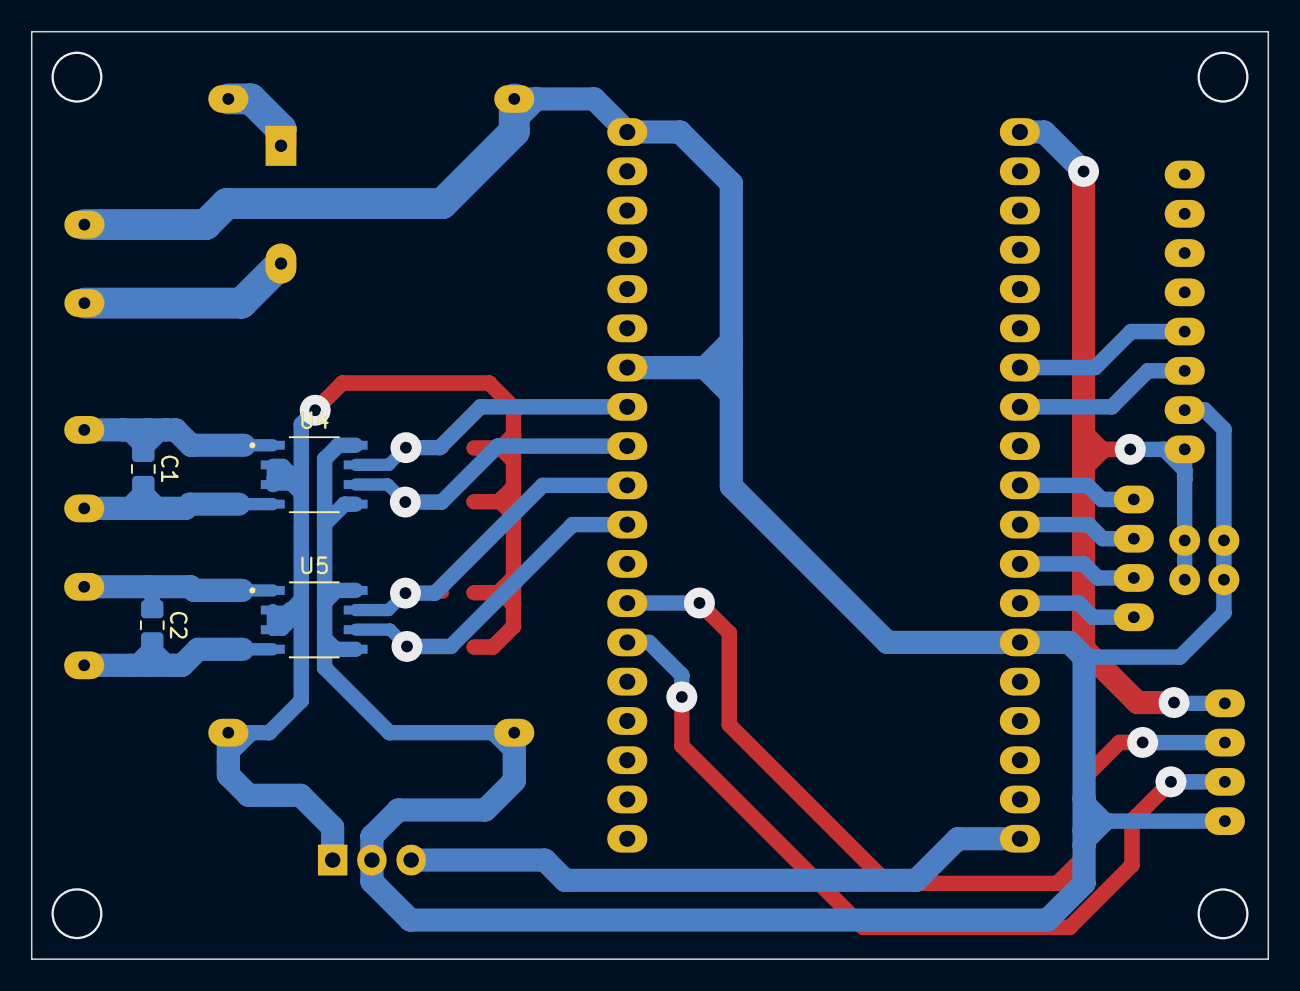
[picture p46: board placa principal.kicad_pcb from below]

Board: 2 copper layers, 80.0 x 60.0 mm, 19 parts (4 on the bottom side), 22 nets.

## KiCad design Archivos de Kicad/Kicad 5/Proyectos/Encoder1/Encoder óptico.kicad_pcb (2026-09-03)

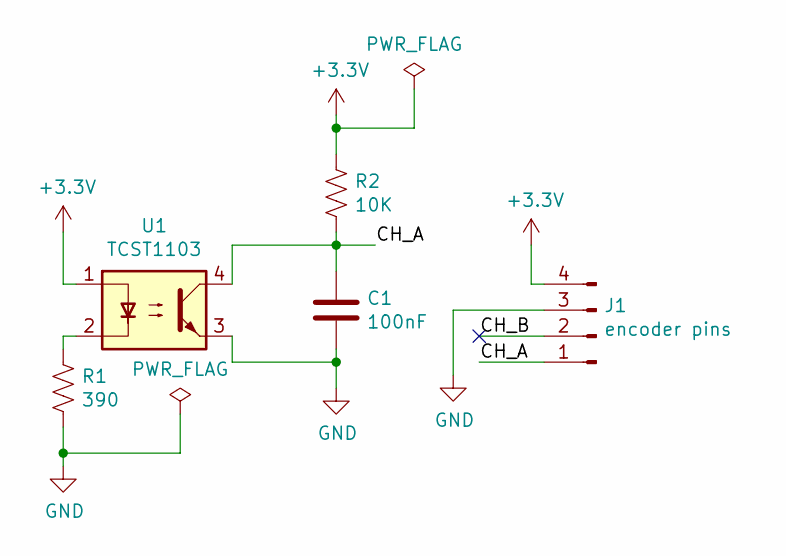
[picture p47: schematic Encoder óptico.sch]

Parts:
C1: 100nF; C_0805_2012Metric_Pad1.18x1.45mm_HandSolder
J1: encoder pins; encoder1_pines
R1: 390; R_0805_2012Metric_Pad1.20x1.40mm_HandSolder
R2: 10K; R_0805_2012Metric_Pad1.20x1.40mm_HandSolder
U1: TCST1103

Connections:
+3V3: J1.4, R2.1, U1.1
/CH_A: C1.1, J1.1, R2.2, U1.4
/CH_B: J1.2
GND: C1.2, J1.3, R1.2, U1.3
unnamed: R1.1, U1.2

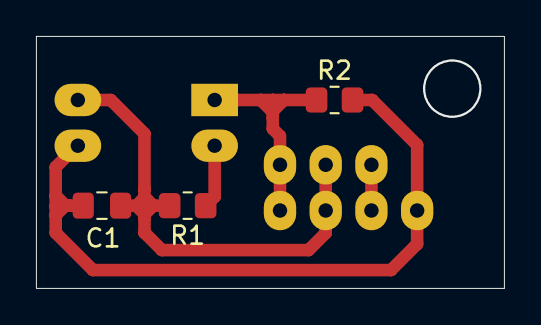
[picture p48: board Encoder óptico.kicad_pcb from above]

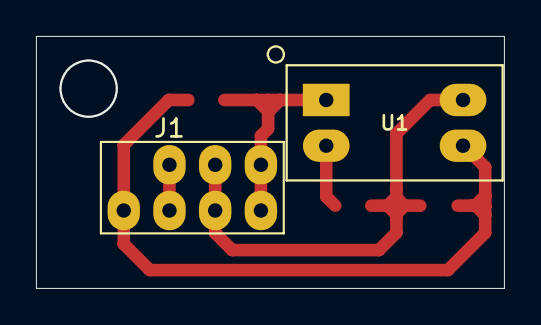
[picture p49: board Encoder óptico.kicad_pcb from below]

Board: 2 copper layers, 26.0 x 14.0 mm, 5 parts (2 on the bottom side), 4 nets.

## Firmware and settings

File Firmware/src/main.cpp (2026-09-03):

#include <Arduino.h>
#include <MPU6050.h>
#include <PID.h>
#include <Motor.h>
#include <Encoder.h>
#include <tuningTools.h>

TaskHandle_t loop2Handle;
void loop2(void* pvParameters);

MPU6050 imu;
PID pid;

Motor m1(19, 18, 0, 1);
Motor m2(5, 17, 2, 3);
Encoder enc1(12, 14);
bool volatile enable = 0;
float volatile ks, ka, kyaw = 0;
float volatile setpoint = 0;

void setup()
{
    
    m1.Setup();
    m2.Setup();
    
    Serial.begin(115200);
    SerialBT.begin("esepe32");
 
    imu.Setup();
 
    //Tasks
    //The main loop runs on core 1, so that we use core 0 for the second loop
    xTaskCreatePinnedToCore(loop2, "loop2", 10000, NULL, 1, &loop2Handle, 0);
    delay(500);
}


void loop()
{
#pragma region communication
  if (SerialBT.available()) {
      String text = SerialBT.readStringUntil('\n');
  //SerialBT añade un espacio al texto, así que es imposible que esté vacío
      if (includedIn("set", text)) { 
        float val = getValue(text);
        if (includedIn("pid", text)) {
             if (includedIn("kp", text)) { 
            pid.Kp = val;
             }
            else if (includedIn("ki", text)) {
            pid.IE = 0;
            pid.Ki = val;
            }
             else if (includedIn("kd", text)) {
            pid.Kd = val;
             }
            else if (includedIn("setpoint", text)) {
                setpoint = val;
            }
            else if(includedIn("enable", text)) {
                enable = (bool)val;
            }
         }
         else if (includedIn("ks", text)) {
            ks = val;
         }
         else if (includedIn("ka", text)) {
            ka = val;
         }
         else if(includedIn("kyaw", text)) {
            kyaw = val;
         }
         else if (includedIn("reset counter", text)) {
            enc1.counter = 0;
         }
      }
      else if (includedIn("get", text)) {
          SerialBT.print("angle = "); SerialBT.println(imu.angle[0]);
          SerialBT.println();
          SerialBT.print("E = "); SerialBT.println(pid.E);
          SerialBT.print("IE = "); SerialBT.println(pid.IE);
          SerialBT.print("DE = "); SerialBT.println(pid.dE);
          SerialBT.println();
          SerialBT.print("Kp = "); SerialBT.println(pid.Kp);
          SerialBT.print("Ki = "); SerialBT.println(pid.Ki);
          SerialBT.print("Kd = "); SerialBT.println(pid.Kd);
          SerialBT.print("ka = "); SerialBT.println(ka);
          SerialBT.print("ks = "); SerialBT.println(ks);
          SerialBT.print("kway = "); SerialBT.println(kyaw);
          SerialBT.println();
          SerialBT.print("PID = "); SerialBT.println(pid.out);
          SerialBT.println();
          SerialBT.print("offset = "); SerialBT.println(pid.offset);
          SerialBT.print("setpoint ="); SerialBT.println(setpoint);
          SerialBT.print("enable = "); SerialBT.println(enable);
          SerialBT.print("counter = "); SerialBT.println(enc1.counter);
          SerialBT.print("speed = "); SerialBT.println(enc1.speed);

      }

    }
#pragma endregion
}
  


void loop2(void* pvParameters)
{
    const uint32_t deltaTime = 2000; //
    const float dt = deltaTime/1000000.f;
    uint32_t timer;
    int sgn = 1;
    while(1)
    {
        timer = micros();

#pragma region logic     
        imu.Update(dt);
        enc1.update(dt*1000);
        pid.offset = ka*enc1.counter + ks*enc1.speed + setpoint;
        pid.Update(imu.angle[0], imu.rate[0], dt);
        m1.SetSpeed((pid.out + kyaw*imu.rate[2])*enable);
        m2.SetSpeed((pid.out*enable-kyaw*imu.rate[2])*enable);
        
#pragma endregion
        while (micros() - timer < deltaTime);

    }
}

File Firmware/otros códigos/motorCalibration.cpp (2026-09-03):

#include <Arduino.h>
#include <Encoder.h>
#include <Motor.h>
#include <tuningTools.h>

Motor motor(19, 18, 0, 1);
Encoder encoder(12, 14);
float deltaTime_ms = 1;
float n_samples = 50;

float GetSpeed(float deltaTime_ms, int n_samples);

void setup()
{
    SerialBT.begin("esepe32");
    motor.Setup();
    encoder.Setup();

}

void loop()
{
    if (SerialBT.available())
    {
        String text = SerialBT.readStringUntil('\n');
        float val = getValue(text);
        if (includedIn("get", text)) {
            if (includedIn("speed", text)) {
                encoder.counter = 0;
                float speed = GetSpeed(deltaTime_ms, n_samples);
                SerialBT.print("speed = "); SerialBT.println(speed);
                SerialBT.print("counter = "); SerialBT.println(encoder.counter);
            }
            else if (includedIn("data", text)) {
                SerialBT.print("dt(ms) = "); SerialBT.println(deltaTime_ms);
                SerialBT.print("n_samples = "); SerialBT.println(n_samples);
            }
            else if (includedIn("points", text)) {
            
                for (int i = 0; i < 10; i++)
                {
                    motor.SetSpeed(100 - 10*i);
                    encoder.counter = 0;
                    float speed = GetSpeed(deltaTime_ms, n_samples);
                    SerialBT.print(i); SerialBT.print("th iteration: duty = ");
                    SerialBT.print(100-10*i);
                    SerialBT.print("    speed = "); SerialBT.println(speed);
                }
            }
        }
        else if (includedIn("set", text))
        {
            if (includedIn("dt", text))
            {
                deltaTime_ms = val;
                SerialBT.print("deltaTime_ms set to "); SerialBT.println(val);
            }
            else if(includedIn("n", text)) {
                n_samples = val;    
                SerialBT.print("n_samples set to "); SerialBT.println(val);
            }
            else if (includedIn("motor duty", text)) {
                motor.SetSpeed(val);
            }
        }
        SerialBT.println();


    }
    delay(10);
}

float GetSpeed(float deltaTime_ms, int n_samples)
{

    float time_ms = 0;
    float angle;
    float ith_sample = 1;

    float sum_t = 0, sum_t2 = 0, sum_a = 0, sum_at = 0;
    SerialBT.print("    Estimated time = "); SerialBT.println(deltaTime_ms * n_samples);
    while (time_ms <= deltaTime_ms * n_samples)
    {
        uint32_t timer = micros();
        encoder.UpdateCounter();
        angle = encoder.counter;

        if (time_ms >= ith_sample*deltaTime_ms && time_ms < (ith_sample+1)*deltaTime_ms)
        {
            sum_t += time_ms;
            sum_t2 += time_ms*time_ms;
            sum_a += angle;
            sum_at += angle*time_ms;

            ith_sample++;    
        }

        while (micros()-timer < 200);
        time_ms += 0.2;
    }


    float speed = (n_samples * sum_at - sum_t*sum_a) / (n_samples*sum_t2 - sum_t*sum_t ) * 1000;
    return speed;
}

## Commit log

2026-09-03 Added old files
    [C_0805_2012Metric.step, DC motor.cfg, DC motor.stp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]
2026-09-03 Create README.md
    Added a README file detailing the self-balancing robot prototypes and their features.
2026-09-03 Enhance README with video link and prototype details
    Added video link of robot movement and updated prototype descriptions.
